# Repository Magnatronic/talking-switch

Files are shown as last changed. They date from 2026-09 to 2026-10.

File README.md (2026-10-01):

# ChatterSwitch – M5StickS3 + Unit Key

Firmware for a big-button accessibility switch: a talking switch (Quick messages), choice-making with Topics,
a Bluetooth/USB keyboard key for an AAC device, and an IR remote (Control), all in one.

## What you need

- M5StickS3
- M5Stack Unit Key (U144) on the StickS3's Grove port – or a 3.5mm switch socket, or a Unit ToF4M distance sensor
  (see *Using a standard 3.5mm switch* and *Touch-free: the ToF sensor*)
- The printed base and cap (`unit-key-big-cap.scad`)
- Arduino IDE 2.x

## Arduino IDE setup

1. **Board package:** Boards Manager → install **esp32 by Espressif Systems**, version 3.3.0 or newer.
2. **Libraries:** Library Manager → install **M5Unified** (it pulls in M5GFX) and **VL53L1X** by Pololu (for the
   ToF distance sensor).
3. **Board:** *ESP32S3 Dev Module*, then set Tools to:

| Setting | Value |
|---|---|
| USB CDC On Boot | **Enabled** – the setup page talks to the switch over it (the firmware won't build without it) |
| Flash Size | 8MB (64Mb) |
| Partition Scheme | Huge APP (3MB No OTA/1MB SPIFFS) |
| PSRAM | OPI PSRAM |
| USB Mode | **USB-OTG (TinyUSB)** (wired USB keyboard + Bluetooth). *Hardware CDC and JTAG* also works, but then the keyboard is Bluetooth only |

These settings are saved in `sketch.yaml` next to each sketch (`TalkingSwitch/` and `ToFTest/`): the Arduino IDE
picks them up when it opens the sketch, and `arduino-cli compile` uses them. If the Tools menu still shows something
else, set it to the table above.

Open `TalkingSwitch/TalkingSwitch.ino` (the sketch keeps its original name; Arduino needs the sketch folder and
`.ino` to share a name). The `partitions.csv` in that folder replaces the
partition layout automatically (2MB for the firmware, ~5.9MB for recordings). Keep it next to the `.ino`.

**Changing the partition layout wipes the recordings and learned IR codes** on the stick at the next upload
(names and settings are kept) – record them again afterwards.

If the screen says **"No PSRAM!"**, change PSRAM to *QSPI PSRAM* and upload again.

In TinyUSB mode the StickS3 still shows up as a COM port (the setup page's Connect list calls it "ESP32S3_DEV –
TinyUSB CDC") and uploads normally reset it automatically. If an upload fails, put the StickS3 into download mode
(see M5Stack's StickS3 docs for the button sequence) and upload again.

## Setup page (USB)

The setup page is `docs/index.html`, published with **GitHub Pages** so anyone setting it up just opens a link in **Chrome or
Edge** (Firefox and Safari can't talk to USB devices). Turn the StickS3 on and plug it in (don't hold the power
button while plugging it in – that starts it for programming), close the Arduino IDE, click **Connect** and pick
**ESP32S3_DEV – TinyUSB CDC**. The switch is set up over the USB cable – no Wi-Fi – and recordings and
typed words stay on the computer.

The page has a tab for each mode – QUICK, TOPICS, KEYBOARD, CONTROL, MOUSE, GAME – then **Voice** and **Settings**, like the
modes on the switch. The tab of the mode the switch is in has a green dot. At the top of each mode's tab is one line:
**In use** (or a **Use** button to switch to that mode), the mode's settings as short chips, and **⚙ settings**,
which opens them (click **?** next to a setting for a one-line explanation; settings that do nothing with the
current choices are hidden). Below that is what the mode uses.

- **Rows:** each message has a name, its length, **▶ Play** (on the switch), **Edit sound** / **+ Add sound**, and
  a **⋯** menu (Listen here, Download .wav, Delete). In QUICK and CONTROL, click a row (or its number) to select it.
- **Sounds, in three steps:** 1 *Make it* – **Type** the words (spoken in the switch's voice; Enter makes it),
  **Record** with the computer's microphone or a headset, or pick an **Audio file**; 2 *Check it* – it plays straight
  away, **▶ Listen** to hear it again; 3 **Save to switch**. It says *Not saved yet* until then, and asks before
  closing without saving. Typing starts from the message's words, or its name; a typed message with no name is
  named after its words.
- **QUICK:** Plays (Selected message / Scan: press twice / Scan: hold & release / Count presses) and the settings
  that go with it; the 4 Quick messages.
- **TOPICS:** Choose from, Choosing, Scan speed, Scan rounds, Stop choice; the 4 **topics** of up to 4 messages
  each (up to 5 seconds per message). With *Choose from: One topic*, **Use** picks the topic.
- **KEYBOARD:** the key (including Left click), a **custom key or shortcut** such as Win+H (dictation) and the
  Bluetooth name; settings: Key action, Press sound, No USB.
- **CONTROL:** 4 remote-control codes, separate from the messages. For each: a name, **Test / Learn**, Delete (⋯),
  and an optional **sound** that the switch says as it sends the code. Settings: IR codes (and scanning settings
  with *Scan*), Press sound.
- **MOUSE:** **Calibrate** (with what it's doing now), a live **Movement** picture (where the stick is, not the
  pointer, and the comfortable range it learnt; **Centre** puts the dot back in the middle), **Pause / Move**, and the connection; settings: Pointer style, Speed left/right, Speed up/down (Follow),
  Speed-up, Steady, Smoothing (Follow), Tilt speed, Dead zone, Directions (Tilt), Dwell click, Switch, Hold to pause, Clutch, Freeze on click, Double-click help, Press sound.
- **Voice:** the switch's **voice** and speed for typed messages and scanning prompts (natural: Emma, Isabella,
  George, Fable; quick: Cori, Alba, Southern English female, Northern English male). It's stored on the switch, so
  every computer uses the same one. Changing it remakes the prompts, and **Remake in this voice** remakes the typed
  messages made in another voice (recorded and uploaded ones don't change).
- **Settings:** the switch's SETTINGS in groups – **Sound** (Volume, Recording boost – which also sets the loudness
  of messages made on the page), **Presses** (Press must last, Ignore repeats), **ToF sensor** (only with one: its
  settings and a live **Sensor test** graph), **Screen and power** (Brightness, Press wakes screen, Sleep after,
  Auto power off), **Switch** (Modes; **Name**: up to 10 characters put in front of the Bluetooth name, e.g. "Sam"
  shows as "Sam ChatterSwitch 7B70"; Forget paired devices) and **About** (firmware, storage – red when nearly
  full, presses since it was turned on, input, USB keyboard). If the page and the switch's firmware don't match,
  the page says **Update the switch** (or to reload the page).
- **Names become prompts:** naming a message, topic or IR code makes its short spoken prompt for scanning, in
  the switch's voice (plus "Back" when choosing from all topics, and "Stop" with Stop choice on). A row says
  *no prompt* when one is missing.

**Typed speech** runs in the browser with two engines. **Kokoro** (the default) sounds much more natural and
takes a few seconds per phrase; **Piper** is almost instant but flatter. Both, and their voices, are served by the
same GitHub Pages site (`docs/tts/`, about 390MB, fetched by `python tools/fetch_tts.py`), so IT only needs to allow
the one `github.io` address. The first use downloads about 115MB for Kokoro (all its voices) or ~80MB per Piper
voice; after that it's cached and works offline. Opening `docs/index.html` straight from disk still does everything
except typed speech.

### Publishing on GitHub Pages

1. Put this folder in a GitHub repository with `git push` (the voice files are ~64MB each: GitHub warns above
   50MB but accepts up to 100MB; they're too big for the web uploader).
2. On GitHub: **Settings → Pages → Build and deployment → Deploy from a branch**, branch `main`, folder **/docs**.
3. After a minute the page is at `https://<account>.github.io/<repository>/`.

To test locally: `python -m http.server 8765 --directory docs`, then open http://localhost:8765.

## Using it

The switch holds **4 Quick messages** (QUICK), **4 Topics of 4 messages** (TOPICS) and **4 IR codes** (CONTROL), each
up to 5 seconds. Each IR code can have its own sound, e.g. IR code 1 "Bubbles" turns the bubble tube on *and* says
"Bubbles!".

**The big switch:** press it. What happens depends on the mode.

| Mode | Big switch does | LED glow |
|---|---|---|
| QUICK | *Plays* setting (and QUICK's *Choosing*): **Selected** – plays the selected Quick message (see *Play style* for hold-to-play and latch; with Tap, keep holding to move to the next Quick message). **Choose one** – by scanning (see below), or by counting presses: 1–4 presses for message 1–4 | message colour: 1 green, 2 blue, 3 purple, 4 orange |
| TOPICS | Messages are **chosen** from the Topics by scanning, see below | colour of the choice on offer |
| KEYBOARD | Holds down the chosen key while pressed. With *No USB* set to QUICK or TOPICS it's also a **backup**: see below | purple |
| CONTROL | Sends the selected IR code, and says its sound if it has one. *IR codes* setting: Selected / Repeat held (keeps sending while held, like a remote's volume button) / Scan (chosen by scanning) | code colour |
| MOUSE | Clicks the mouse button; head or hand movement moves the pointer. See *MOUSE* below | pink |
| GAME | A gamepad button; head or hand movement is a thumbstick (USB). Off at first. See *GAME* below | blue |
| SETTINGS | Keeps doing whatever the previous mode did | as previous mode |

### Touch-free: the ToF sensor

Plug an M5Stack **Unit ToF4M** distance sensor into the Grove port instead of the Unit Key (not together with the
Unit Key or a jack switch – they share the Grove pins) and restart: the switch finds it by itself and it becomes the
switch – every mode, scanning, Press must last and Ignore repeats work as with a button.

- **Line:** a press is coming closer than the *Distance*.
- **Move:** a press is a movement of the *Movement* size towards the sensor from where the hand or finger rests –
  the resting place is learnt as it goes (*Follow*), so it suits small movements like a finger and copes with the
  user shifting. After it has been pressed for the *Settle* time, where the finger is becomes the new resting
  place and it lets go.
- One reading past the line presses (a quick wave counts); it reads about 65 times a second.
- **Setting it up:** SETTINGS → *Sensor test* shows a live graph on the stick, and the setup page's Settings tab
  has a bigger live graph next to the sensor settings, with **Record** to download the readings as a spreadsheet
  file for assessment.
- A finger works best 5–10 cm away; closer than about 4 cm counts as pressed. Mount it rigidly, keep its window
  clean, and point it at a plain background.
- With the sensor there's no switch LED (feedback is on screen and by sound), and the switch doesn't sleep – the
  sensor can't wake it – so the battery runs down faster.

### Just a talking switch

For a switch that only needs to talk, set SETTINGS **Modes: Talking only**: A then goes QUICK → TOPICS →
SETTINGS, and the setup page shows only QUICK, TOPICS, Voice and Settings.

### MOUSE: head or hand movement moves the pointer

The stick's motion sensor works a mouse pointer (SETTINGS **MOUSE mode: Off** hides it), worn on the head (headband or
cap) or on a hand, using whatever movements the user makes (learnt by Calibrate). It goes over USB, or Bluetooth
with the same pairing as KEYBOARD (on an iPad, if no pointer shows, turn on AssistiveTouch).

- **Calibrate:** the first time MOUSE starts, and whenever you choose it (B to **Calibrate**, hold A; or the setup
  page). Wear it as it will be used; it works whichever way round it's worn.
  1. *Keep still* – sit comfortably. This position is the middle.
  2. *Right*, 3. *Left*, 4. *Down*, 5. *Up* – each as far as is comfortable, and back. A beep starts each one;
     the screen shows how far it has gone. It can be any movement: a head turn or nod, a wrist roll or bend.
  From the whole left-to-right and down-to-up range it sets **Speed left/right** and **Speed up/down**, so a full
  comfortable movement crosses about the screen (the screen shows the speeds it chose). They're ordinary settings:
  change them after if needed, e.g. lower for small targets. If a movement isn't seen within 10 s it moves on (Left
  or Up then get the same range as the other side; without Right or Down it keeps the old calibration and speeds). Each time MOUSE starts after that it only needs *Keep still* (a second), unless it's worn at a
  clearly different angle, when it asks for the whole calibration again.
- **Pointer style:** *Follow* (at first): the pointer moves as you move. *Tilt*: like a joystick – hold a little
  away from rest and the pointer keeps going, faster the further you go (full speed at about 70% of the comfortable
  range, so no need to reach the limit); back to rest and it stops. Tilt needs only small movements and has no
  screen-edge problem. Its settings: *Tilt speed*, *Dead zone* (how close to rest keeps still) and *Directions*
  (*4 only*: straight left, right, up or down, never at an angle). Rest is where you are after *Keep still*, after
  a pause, or after **Centre** on the setup page. Nods and wrist rolls are checked against gravity, so they don't
  drift; a head turn can drift a little, and while you rest it slowly settles back.
- **Screen edges** (Follow): the pointer stops at the edge while the head keeps going. That's also how to bring the pointer
  back in line: push into the edge until the head is comfortable again, or use the clutch (below).
- **Clicks:** the big switch is the left (or right, *Switch* setting) button. **Dwell click:** keep the pointer in
  one small area for the *Dwell click* time to click; move away to click again. A green bar on the screen fills up
  before it clicks.
- **Pause:** hold A, or **hold the switch** for the *Hold to pause* time (2 s): two falling notes = paused, two
  rising = moving. With Hold to pause on, a short press clicks when it's let go; set it Off to drag (the button is
  then held while the switch is).
- **Clutch** (with Hold to pause on): holding the switch keeps the pointer still. To bring the pointer back in line,
  hold the switch, turn to look at the pointer (or back to comfortable), and let go: a low note says it won't click.
  Like lifting a mouse off the desk. Moving less than the *Clutch* amount (10°) while holding is still a click.
- **Freeze on click:** the pointer keeps still for a moment (0.3 s) when the switch is pressed and let go, so the
  press doesn't jog it. With Hold to pause on, it also keeps still while the switch is held, so the click lands where
  it was pressed.
- **Double-click help** (off at first): after a click the pointer keeps still for a while (0.5–1.5 s), so a second
  click lands in the same place. It doesn't double-click by itself.
- It doesn't sleep in MOUSE mode.
- The research and step-by-step plan are in [MOUSE-PLAN.md](MOUSE-PLAN.md).

### GAME: head or hand movement is a gamepad thumbstick

Off at first: SETTINGS **GAME mode: On** adds it (the switch restarts, as USB has to start again with the gamepad).
Over **USB only**, the stick is then also a gamepad:
- **On a PC:** it shows in *Set up USB game controllers* (joy.cpl) with no driver. Games that only take Xbox
  controllers need Steam Input (or similar) to use it.
- **On an Xbox:** plug it into a USB port on the **Xbox Adaptive Controller**. Its left stick is the XAC's left
  stick, its right stick the right one. The XAC's USB ports only give a little power unless the XAC has its own
  power supply; the stick can run on its battery.

How it works:
- **Calibrate** is the same as MOUSE (shared, so calibrating in either does both). Rest is the thumbstick in the
  middle; full push comes at about 70% of each side's comfortable range, so a stiff side still gets there.
- Near rest (*Dead zone*) the thumbstick stays in the middle; *Response* makes it finer near the middle.
  *Directions: 4 only* pushes straight left, right, up or down. Nods and wrist rolls don't drift (gravity); a head
  turn settles back to the middle while resting near it.
- **The switch** is a gamepad button (*Switch button*: A, B, X, Y, LB, RB), held while the switch is.
- **Pause:** hold A, or **Pause** on the setup page: the thumbstick goes to the middle. Moving again makes where you
  are the new rest.
- Not over Bluetooth, and it doesn't sleep in GAME mode.

### Backup mode: a switch for the AAC device, and a talker when it isn't there

With KEYBOARD's **No USB** set to QUICK or TOPICS, the switch works an AAC device over USB, and when
there's no USB connection (the device isn't there, is flat, or the cable is out) for 10 seconds it changes to
QUICK or TOPICS by itself, with a falling two-note sound and "No USB" on screen, so it can still talk.
While counting down, the KEYBOARD screen says "No USB – QUICK in 8 s". In the backup mode the bottom line starts
with "Backup", and Bluetooth stays off, so it doesn't use extra battery (and the switch can sleep as usual).
When USB is connected again it goes back to KEYBOARD (rising two notes), once any choice being made is
finished. If it's asleep, that happens when it wakes. Choosing a mode with A (or on the setup page) ends the
backup. Fill the Quick messages and topics with what's needed when the AAC device isn't there.

### Stick buttons – one rule everywhere

The bottom line of the screen always shows what the buttons do right now.

| Button | Does |
|---|---|
| **A click** | Next mode (QUICK → TOPICS → KEYBOARD → CONTROL → MOUSE → GAME → SETTINGS, skipping modes turned off in *Modes* / *MOUSE mode* / *GAME mode*). In a mode's settings, an open topic, About or Sensor test: close it |
| **B click** | Next: Quick message / topic / key / IR code / Calibrate (MOUSE, GAME), then the mode's **Settings** item, then back to the first. In an open topic: its next message. In settings: the next setting. B itself is silent, to save battery |
| **Hold A** | Do it: QUICK – record the selected Quick message (release to stop; if it already has one, the screen says "Hold A again to replace" – hold A again within 4s to record, B keeps it); TOPICS – open the topic, to look through its messages; CONTROL – learn the selected code (remote 30cm+ from the end of the stick, within 8s); MOUSE, GAME – pause / move the pointer (thumbstick), or on **Calibrate** start it; on **Settings** – open them; in settings – next value, or open About / Sensor test |
| **Hold B** | Hear it: QUICK – the selected Quick message; an open topic – the message; CONTROL – the code's sound (without sending it); in settings – back a value |

A hold is 0.6s. When the screen is off, the first press of A or B only wakes it; when it's just dim, presses work
as normal.

### Scanning: choice-making with one switch

With QUICK's *Plays* set to **Choose one** (Press twice or Hold & release) or CONTROL's *IR codes* to **Scan**, and in TOPICS, the switch offers the choices one at a time – each with
its LED colour, its name on screen and a short **spoken prompt** played quietly ("Toast"… "Crisps"… "Yoghurt") –
and one is picked, which then plays in full (or, in CONTROL, is sent).

- **QUICK, Plays: Choose one** – it offers the 4 Quick messages. The simplest start.
- **TOPICS, Choose from: One topic** (default) – it offers the messages in the selected topic (B on the switch, or *Use* on the
  setup page), e.g. "Snack time".
- **TOPICS, Choose from: All topics** – it offers the **topics** first ("Snack time"… "Music"…), then the chosen topic's
  messages and **"Back"** (to return to the topics).
- **Offer Quick / Offer Control / Offer My device** (with All topics) – more choices next to the topics, so TOPICS
  can be the home screen: **Quick** offers the Quick messages and **Control** the IR codes, like a topic's
  messages (then Back), so the user can say a Quick message or turn on the bubble tube or TV themselves; **My
  device** changes the switch to KEYBOARD so they can use their AAC device or computer.
  Once in KEYBOARD every press goes to the device, so the switch can't offer a way back: bring it back with A (or
  the setup page), or with *No USB: TOPICS* it comes back by itself when USB is unplugged.
- **Choosing: Press twice** – a press starts the offers, the next press chooses. With no choice it stops after the
  set number of *Scan rounds*.
- **Choosing: Hold & release** – hold the switch to step through the offers, let go to choose. After choosing a
  topic, hold again for its messages.
- **Stop choice: On** – every scan ends with **"Stop"** (LED red): the topics, a topic's messages (after "Back"),
  and QUICK's and CONTROL's choices. Choosing it ends the scan without doing anything; the next press starts again
  from the top. It lets the user say "none of these". A or B on the stick also stops a scan.

Only topics and messages that are set up are offered, so two messages make a simple two-way choice. Prompts are
made by the setup page from the **names**. A message without a prompt – e.g. one just recorded on the stick – plays
itself quietly as its prompt (cut short by the next offer), so scanning works straight away with no setup page:
record the Quick messages (QUICK, hold A) and set QUICK's *Plays: Choose one*.

### Settings

Each mode has its own settings – press B until the screen shows **Settings**, then hold A to open them – and the
**SETTINGS** mode holds the general ones. In any settings: **B** = next setting, **hold A** = next value, **hold B** = back a value,
**A** = close (or next mode). Changes are saved straight away; settings close by themselves after 30s untouched.
Settings that do nothing with the current choices are left out (e.g. Scan speed when the selected message plays).
All of these are on the setup page too, on each mode's tab and the Settings tab.

| Where | Setting | Choices (default **bold**) | What it does |
|---|---|---|---|
| General | Volume | 1, 2, **3**, 4 | How loud messages play |
| General | Modes | **All**, No KEYBOARD, No CONTROL, Talking only | Turn KEYBOARD and/or CONTROL off for a switch that only talks: A skips them, the setup page hides their tabs, and their settings (and the matching Offer settings) go too. Their key and IR codes are kept |
| General | MOUSE mode | Off, **On** | The MOUSE mode (see above) and its tab on the setup page. Off: A skips it and the tab is hidden |
| General | GAME mode | **Off**, On | The GAME mode (see above) and its tab. The switch restarts when it changes. Needs USB Mode: USB-OTG (TinyUSB) |
| General | Press must last | **Instant**, 0.1s, 0.25s, 0.5s, 1s | Filters accidental brushes |
| General | Ignore repeats for | Off, 0.2s, **0.4s**, 0.8s, 1.5s | Filters tremor and bounces after a press |
| General (sensor) | Sensor mode | Line, **Move** | Only with a ToF sensor plugged in – see *Touch-free: the ToF sensor* |
| General (sensor) | Distance | 5, 6, 8, **10**, 15, 20, 30, 50 cm | Line: closer than this counts as a press |
| General (sensor) | Movement | 5, **8**, 10, 15, 20, 30 mm | Move: a movement this big towards the sensor counts as a press |
| General (sensor) | Settle | Off, 1, **2**, 3, 5 s | Move: after being pressed this long, where the finger is becomes the new resting place and it lets go. Off for users who hold presses on purpose |
| General (sensor) | Follow | Slow, **Medium**, Fast | Move: how quickly the resting place follows drift |
| General (sensor) | Ignore beyond | Off, 20, **30**, 50 cm | Anything further away counts as nothing there |
| General (sensor) | Sensor test | hold A | A live graph of the sensor with a press count; presses only beep there. B restarts the count, A closes |
| General | Brightness | Low, **Medium**, High | Screen brightness while in use. Low saves battery |
| General | Press wakes screen | **No**, Yes | Whether presses of the big switch light up the screen |
| General | Sleep after | Off, 2 min, **5 min**, 15 min | On battery, with no presses: sleep to save power. The big switch still works (see below) |
| General | Auto power off | **Never**, 30 min, 60 min, 2 hours | On battery, with no presses: turn off completely, e.g. at the end of the day |
| General | Recording boost | Off, Low, **Medium**, High | Makes recordings made on the switch louder, at the cost of some harshness |
| General | Forget BT devices | hold A, then again to confirm | Clears every paired computer/tablet. Also remove the switch in that device's Bluetooth settings |
| General | About | hold A to open | The firmware version, the switch's name, how much recording storage is used, presses since it was turned on, and the input (switch or ToF sensor). A closes |
| QUICK | Plays | **Selected**, Choose one | *Selected*: plays the selected Quick message (Play style and Hold for next msg apply). *Choose one*: one is chosen – see QUICK's Choosing. The setup page shows Plays and Choosing as one setting |
| QUICK | Choosing | **Press twice**, Hold & release, Count presses | Kept in step with TOPICS and CONTROL's Choosing (change Press twice / Hold & release in one and the other follows); only Count presses is QUICK's own – TOPICS and CONTROL (and the Quick choice inside TOPICS) always scan. *Press twice* / *Hold & release*: scanning, see above (Scan speed, Scan rounds, Stop choice apply). *Count presses*: press 1–4 times quickly for message 1–4 – each press ticks and the LED shows that message's colour; the message plays after the Press gap. Not for users with tremor or accidental double presses |
| QUICK | Press gap | 0.5s, **0.8s**, 1.2s, 1.6s, 2s | Count presses: how long without a press ends the count – longer for users who are slower to release and press again (every message waits this long before playing). Ignore repeats only filters bounces under 0.15s in this mode |
| QUICK | Play style | **Tap**, Hold to play, Latch | *Tap*: a press plays the whole message. *Hold to play*: plays (looping) only while the switch is held – classic cause and effect. *Latch*: one press starts it looping, the next press stops it |
| QUICK | Hold for next msg | Off, 1s, **1.5s**, 2s, 3s | With Tap: how long the switch is held to move to the next Quick message. Turn off if letting go quickly is hard |
| TOPICS | Choose from | **One topic**, All topics | See above |
| TOPICS | Offer Quick | **Off**, On | With All topics: offers "Quick" (the Quick messages) next to the topics, see above |
| TOPICS | Offer Control | **Off**, On | With All topics: offers "Control" (the IR codes) next to the topics |
| TOPICS | Offer My device | **Off**, On | With All topics: offers "My device" (changes to KEYBOARD) next to the topics |
| TOPICS, CONTROL | Choosing | **Press twice**, Hold & release | See above |
| QUICK, TOPICS, CONTROL | Scan speed | 1.5s, 2s, **3s**, 4s, 5s | How long each choice is offered |
| QUICK, TOPICS, CONTROL | Scan rounds | 1, **2**, 3 | Press twice: how many times round before it stops by itself |
| QUICK, TOPICS, CONTROL | Stop choice | **Off**, On | Offers "Stop" last, to choose none of them |
| KEYBOARD | No USB | **Bluetooth**, QUICK, TOPICS | What to do when the switch isn't plugged into a computer or AAC device by USB. *Bluetooth*: send the key over Bluetooth instead. *QUICK* / *TOPICS*: after 10 seconds, talk instead, using that mode – Bluetooth stays off to save battery. Plugging USB back in switches it back to KEYBOARD (see the backup mode above). Only with USB Mode: USB-OTG (TinyUSB) |
| KEYBOARD | Key action | **Momentary**, Latch | *Momentary* holds the key while the switch is held; *Latch* – one press holds the key down, the next lets it go. The screen says "Key held" and the LED glows brighter while latched |
| KEYBOARD, CONTROL, MOUSE, GAME | Press sound | **Off**, Click, Beep | A sound on each press, as feedback (CONTROL: only for codes with no sound of their own) |
| CONTROL | IR codes | **Selected**, Repeat held, Scan | See the CONTROL mode above |
| MOUSE | Pointer style | **Follow**, Tilt | Follow: the pointer moves as you move. Tilt: hold away from rest and it keeps going; back to rest and it stops |
| MOUSE | Tilt speed | 1–5 (**3**) | Tilt: the fastest the pointer goes |
| MOUSE (Tilt), GAME | Dead zone | 2°, **4°**, 6°, 9° | This close to rest nothing moves (shared) |
| MOUSE (Tilt), GAME | Directions | **Any**, 4 only | 4 only moves straight left, right, up or down (shared) |
| MOUSE | Speed left/right, Speed up/down | 1–8 (**4**, **3**) | How fast the pointer moves each way. Calibrate sets them so a full comfortable movement crosses the screen; change them after if needed. The computer's pointer speed also applies |
| MOUSE | Speed-up | Off, Low, **Medium**, High | Faster movements go further, so slow ones stay precise |
| MOUSE | Steady | Off, **Low**, Medium, High | Ignores turns slower than this – steadies tremor and drift |
| MOUSE | Smoothing | Off, **Low**, Medium, High | Smooths out shakes, with a little lag |
| MOUSE | Dwell click | **Off**, 0.8, 1, 1.5, 2, 3 s | Time in one place to left-click |
| MOUSE | Dwell area | Small, **Medium**, Large | How far the pointer may wander and still count as one place |
| MOUSE | Switch | **Left click**, Right click | The button the big switch presses |
| MOUSE | Hold to pause | Off, 1 s, **2 s**, 3 s | Holding the switch this long pauses / moves the pointer; short presses click when let go. Off: the button is held while the switch is (drag) |
| MOUSE | Clutch | Off, 5°, **10°**, 15° | With Hold to pause on: the pointer keeps still while the switch is held; moving more than this while holding re-lines the head, with no click |
| MOUSE | Freeze on click | Off, 0.2 s, **0.3 s**, 0.5 s | The pointer keeps still this long when the switch is pressed and let go (and while held, with Hold to pause on) |
| GAME | Stick | **Left**, Right | Which thumbstick the movement is |
| GAME | Switch button | **A**, B, X, Y, LB, RB | The gamepad button the switch is, held while the switch is |
| GAME | Response | Straight, **Gentle**, Very gentle | Gentle: finer near the middle, full at the comfortable limit |
| MOUSE | Double-click help | **Off**, 0.5 s, 1 s, 1.5 s | After a click the pointer keeps still this long, so a second click lands in the same place |

### The screen

- **Top bar:** the mode, in its colour ("SETTINGS" on that colour while its settings are open); on the right, the
  volume (a speaker and 4 bars) and the battery (% and icon; green bolt = charging, red = low).
- **Middle:** three lines, the same on every screen – the main thing (big), its state or what to do (green ready,
  orange a problem, yellow what to do), and details (grey). What the switch will do – the Quick message; in TOPICS the topic B is on and its messages (or the
  choice on offer while scanning); the key and whether it's sending by USB or Bluetooth; or the IR code. When scanning, QUICK and
  CONTROL still show the selected message or code (the one B and hold A work on), with "Scans…" underneath.
- **Bottom:** what the buttons do right now.
- A white frame appears while the big switch is held down.

Recordings are trimmed and boosted automatically, stored in flash, and survive power-off.

**To delete a Quick message:** select it (B in QUICK), then hold A, and hold it again ("Hold A again to replace") for a couple of seconds *without speaking*, and
let go. The screen says "Nothing heard – cleared". Or use ⋯ › Delete on the setup page (topic messages are made there).
Mode, selected Quick message, topic and IR code, key and settings are remembered too.

**Recording tips:** speak 10–15cm from the stick in a normal voice. The recording is cleaned up automatically:
silence trimmed, hiss between words turned down, level evened out.

### Keyboard (USB or Bluetooth)

Keys: **Space, Enter, Up, Down, Left, Right, Left click**, and a custom key or shortcut set on the setup page (B-click to choose). In Grid 3 / Mind Express,
set switch input to the key shown on screen.

**Left click** clicks the left mouse button wherever the pointer is (it doesn't move the pointer). With *Key action:
Latch* it holds the button down until the next press, for dragging. On an iPad the pointer only shows with
AssistiveTouch on.

- **USB:** plug into the computer with a data cable. Nothing to pair, and it charges at the same time.
- **Bluetooth:** the StickS3 appears as **"ChatterSwitch XXXX"** – each stick has its own 4-character ID, shown on the
  KEYBOARD screen, so you can tell switches apart – with any *Switch name* from the setup page in front, e.g.
  "Sam ChatterSwitch 7B70". Pair it from Windows, iPad or Android like a keyboard (it's a keyboard and mouse in
  one, for Left click).
  To move it to a different computer or tablet, use *Forget BT devices* in SETTINGS.
  **Paired before Left click was added (28 Sep 2026)?** Remove the switch in the device's Bluetooth settings, use
  *Forget BT devices* on the stick, and pair again – the device remembers it as keyboard-only.

It picks automatically: when a computer is using it as a USB keyboard, keys go over USB only;
otherwise over Bluetooth. A phone charger doesn't count, so Bluetooth keeps working while charging.
The screen says which is in use.

### Power saving

- The screen dims after 30s and switches off after 2 minutes without a press of A or B. Its brightness while
  in use is the *Brightness* setting (Low saves the most).
  The big switch keeps working with the screen off.
- Bluetooth only runs in KEYBOARD and MOUSE modes (it starts after a second or so in that mode; pairing is remembered).
- **Sleep:** on battery, after the *Sleep after* time with no presses, the StickS3 sleeps – screen, speaker
  and radio off. The switch LED keeps glowing. **The big switch still works:** a press wakes it and does its
  job (a fraction of a second slower than normal). A or B wakes it too.
  It doesn't sleep in KEYBOARD mode over Bluetooth, because the connection would drop, in MOUSE or GAME mode, or with the
  ToF sensor, which can't wake it.
- **Auto power off** (off by default): after the chosen time with no presses it beeps three times and shows
  a warning; 30s later it powers off. Press any button to cancel. Press the power button to turn it back on.
- It never sleeps or powers off while plugged into USB.
- A "Low battery" warning appears at 15%.

### Press logging

Every press of the big switch is written to the USB serial port (115200 baud) as
`press,<milliseconds since boot>,<mode>` – handy evidence for assessing
intentional communication. SETTINGS → About (and the setup page's About box) shows how many since it was turned on.

## Tuning in code

Most settings are in the SETTINGS mode above. At the top of `TalkingSwitch.ino`:

| Setting | Default | What it does |
|---|---|---|
| `DEBOUNCE_MS` | 25 | Contact bounce filter |
| `MAX_SECONDS` | 5 | Longest recording per message |
| `MIC_PGA` | 8 | Microphone analogue gain (3dB steps, 0–10). Lower it if loud voices sound distorted |
| `SCREEN_DIM_MS` / `SCREEN_OFF_MS` | 30000 / 120000 | Screen dims, then switches off, when idle |
| `BLE_NAME` | "ChatterSwitch" | Default Bluetooth name; each stick's own ID is added to it |
| `FW_VERSION` / `FW_API` | "30 Sep 2026" / 3 | Version shown in About. Raise `FW_API` (and `PAGE_API` in `docs/index.html`) when the page and firmware must change together |

## Troubleshooting

- **Won't compile, with errors about `io_pin_remap.h`, `pinMode` or `tone` in M5Unified:** the board is set to
  *Arduino Nano ESP32*. Choose **Tools → Board → esp32 → ESP32S3 Dev Module** and the settings above.
- **Won't compile: "Set Tools > USB CDC On Boot: Enabled":** set **Tools → USB CDC On Boot → Enabled** (and check
  the other settings above). The IDE keeps Tools settings between sketches, so they can change while you're working
  on another one. MouseTest uses the same settings.
- **Big switch does nothing:** with a jack switch, try the other Grove wire (see below). With the Unit Key, swap
  `PIN_KEY` (10) and `PIN_LED` (9) in the code – the Grove wire order can vary. With the ToF sensor, check About
  says *Input: ToF sensor* – the switch only looks for it when it starts, so plug it in, then turn it on.
- **Recordings hiss or distort:** hiss – speak closer and lower Recording boost; distortion on loud voices – lower `MIC_PGA`.
- **IR only works close up:** the StickS3's IR LED is small (it's in the end of the stick). Point that end straight at
  the device – its IR window is usually on the front – ideally within 3–5m. In a dark sensory room, bouncing off a
  white wall or ceiling can help. For longer range, an IR repeater/extender near the device works with any remote.
- **IR learns nothing:** make sure the remote is 38kHz (most TV remotes are) and point it at the StickS3's IR window from **30cm to 1m** – closer than 30cm can scramble the code. Very long air-con codes may be cut short.
- **Quiet playback:** raise *Volume* in SETTINGS (or on the setup page's Settings tab); for a noisy classroom add
  a small external speaker.
- **After an upload the switch shows as "USB JTAG/serial debug unit" and doesn't answer:** it's waiting in download
  mode instead of running the firmware – press the stick's power button once to restart it. It then shows as
  "ESP32S3_DEV – TinyUSB CDC" on a different COM port.
- **The page says the switch didn't answer:** check *USB CDC On Boot: Enabled* and close the Arduino Serial Monitor.
  The Connect list always calls the switch "ESP32S3_DEV – TinyUSB CDC" (the switch's own name is used for Bluetooth).
- **Using a standard 3.5mm switch instead:** cut a Grove cable and wire a 3.5mm mono socket to two of its wires:
  **yellow** (the switch signal, GPIO10) and **black** (ground) – either way round, as a switch just joins them. Cut the
  red (5V) and white wires short and cover them. If it doesn't respond, colours vary between cables: try white instead
  of yellow. The thin wires hold better in screw terminals if twisted and folded back. Not together with the ToF sensor
  (it uses the same wires).

## ToF sensor test (touch-free switch)

`ToFTest/ToFTest.ino` is a separate test sketch for the M5Stack **Unit ToF4M** (VL53L1X) on the Grove port, to try it as
a touch-free switch (a hand, head or foot moving closer than a set distance) and to watch a user's movement. It
needs the **VL53L1X** library by Pololu (Library Manager). Unplug the Unit Key and any switch on the mono jack first –
they share the Grove pins. Two ways to press: **LINE** – closer than a set distance (5–50 cm); **MOVE** – a movement of 5–30 mm towards the
sensor from where the hand or finger rests (best for small movements like a finger). The screen shows a scrolling
graph that zooms to fit, with the trigger line. A = size, hold A = LINE / MOVE, B = reset, **hold B = settings**
(B next, hold A change, A close):

| Setting | Choices | What it does |
|---|---|---|
| Mode | LINE, **MOVE** | How a press is detected |
| Distance | 5, 6, 8, **10**, 15, 20, 30, 50 cm | LINE: press closer than this |
| Movement | 5, **8**, 10, 15, 20, 30 mm | MOVE: press on a movement this big towards the sensor |
| Settle | Off, 1, **2**, 3, 5 s | MOVE: after being pressed this long, where the finger is becomes the new resting place (so it can't stay stuck pressed) |
| Follow | Slow, **Medium**, Fast | MOVE: how quickly the resting place follows drift. Slow catches slow presses; Fast copes with restless movement |
| Ignore beyond | **Off**, 20, 30, 50 cm | Anything further away counts as nothing there – stops people passing by from pressing |
| Field of view | **Wide**, Medium, Narrow | Narrower ignores movement at the sides, but the finger must be right in front |
| Smoothing | **Off**, 3 readings | The middle of the last 3 readings: removes single spikes, ~30 ms later |
| Too close | **Pressed**, Nothing | Closer than the sensor can measure (~4 cm) |
| Range | **Short**, Long | Short: up to ~1.3 m, ~65 readings a second, better in sunlight. Long: ~4 m, slower |

The sensor isn't reliable closer than about 4 cm, and a finger works best 5–10 cm away. Mount it rigidly, keep its
window clean, and point it at a plain background. Readings also go to the serial port for the Serial Plotter – open it
after the stick has started.

## Mouse test (motion sensor as a mouse)

This is now ChatterSwitch's MOUSE mode (above); the test sketch stays for trying new ideas first.
`MouseTest/MouseTest.ino` is a separate test sketch: the StickS3's motion sensor moves the pointer, worn on the head
(headband or cap) or held in the hand. Turn left/right to move left/right, tip down/up to move down/up. It works over
USB, or Bluetooth as "ChatterSwitch XXXX" (the same identity as ChatterSwitch, so a paired device keeps working).

- **Clicks:** the big switch is the left button (held while the switch is, so it drags) or the right button
  (*Switch* setting). **Dwell click:** keep the pointer in one small area for the *Dwell* time to click; move away to
  click again.
- **Calibrate** (hold A; also at the first start): *Keep still*, then *Tip down* – nod down or tip the front down,
  then back. This works whichever way round the stick is worn – calibrate it the way it's worn. Later starts
  only need *Keep still*, unless it's worn at a clearly different angle, when it asks for *Tip down* again.
- **Buttons:** A = pause / move, hold A = calibrate, B = next speed, hold B = settings (B next, hold A change,
  A close).
- The screen shows the turn as a dot in a box (the grey ring is *Steady*). The rates also go to the Serial Plotter.

| Setting | Choices | What it does |
|---|---|---|
| Speed | 1–6 (**4**) | How far the pointer goes per turn. The computer's pointer speed also applies |
| Speed-up | Off, Low, **Medium**, High | Faster turns go further, so slow turns stay precise |
| Steady | Off, **Low**, Medium, High | Ignores turns slower than this – steadies tremor and drift |
| Smoothing | Off, **Low**, Medium, High | Smooths out shakes, with a little lag |
| Dwell click | **Off**, 0.8, 1, 1.5, 2, 3 s | Time in one place to click |
| Dwell area | Small, **Medium**, Large | How far the pointer may wander and still count as one place |
| Switch | **Left click**, Right click | What the big switch does |
| Flip left/right, Flip up/down | **Off**, On | If the pointer goes the wrong way |

## Notes

- Compile-checked against esp32 core 3.3.11 with M5Unified 0.2.23 / M5GFX 0.2.30 and VL53L1X 1.3.1, in both USB
  modes.
- Tested on hardware: the Unit Key and a 3.5mm jack switch, the modes and their settings, the setup page, and the
  ToF sensor (Line and Move), IR (learning and sending), Left click over USB. Not yet tested on hardware: Left click
  over Bluetooth, the USB keyboard, sleep, auto power-off and the backup
  mode.
- This is a DIY device, not a certified AT product. Check it's robust and safe for each user before use.

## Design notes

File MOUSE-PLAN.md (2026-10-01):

# MOUSE mode – research and plan

This is where the ChatterSwitch MOUSE mode stands and what comes next, so work can pick up from here.
We build it **one step at a time**, testing each step on the stick before starting the next.
New ideas can be tried in `MouseTest/` first.

**Targets:** Windows PCs and iPads (USB, or Bluetooth with the same pairing as KEYBOARD).
**Users:** college; the stick is worn on the head (headband or cap) or on a wrist or hand.

## Status

| Step | What | State |
|---|---|---|
| 1 | MOUSE mode in ChatterSwitch (from MouseTest), hold to pause, setup page tab | **Done, tested 30 Sep 2026** (commits 369e680, a447b3f; on by default) |
| 2 | Training on the user's own movements, speeds set by Calibrate, live picture on the page | **Built 30 Sep–1 Oct 2026, to test** (no turn limit, see below) |
| 3 | Freeze on click, double-click help, clutch | **Built 1 Oct 2026, to test** (ignore jerks and Centre dropped) |
| 4 | Tilt (joystick) style for very small movements | **Built 1 Oct 2026, to test** |
| 5 | True screen position (absolute pointer) | Only if 2–4 aren't enough |
| 6 | GAME mode: movement as a thumbstick, for PC and Xbox | **Built 1 Oct 2026, to test** (straight into ChatterSwitch, no GameTest) |
| – | Head gestures (Quha style) | Idea, see the end |

## What we found (research, 30 Sep 2026)

**The edge problem.** The stick sends "move by this much", like any mouse, so it never knows where the pointer is.
At the edge of the screen the pointer stops but the head keeps turning; turning back moves the pointer straight
away, so "straight ahead" has shifted and the user ends up looking sideways at the screen.
- The commercial gyro head mice (**Quha Zono**, **GlassOuse**) behave the same way. Their manuals present it as the
  way to re-centre: push the pointer into the edge on purpose and keep turning. Fine as a trick, a fault by accident.
- Quha also has head gestures for pause, scroll and **cursor centring**, separate horizontal/vertical speed, and a tremor filter.

**Comfortable movement.** Comfortable head turn is about ±30°, and the maximum is about ±55°. Nodding range is smaller.
People with CP often move further one way than the other. One person testing a head-worn IMU joystick had a sore
neck after 10 minutes, so keep the movement needed small and make pausing easy.
- The current default (Speed 4 = 30 counts/°) needs about ±32° to cross a 1920-pixel screen, right at the comfortable limit.

**Two ways to map movement to the pointer:**
- **Follow (position/velocity of the turn → pointer movement):** what we have now. Fast.
- **Tilt / joystick (angle from rest → pointer speed):** hold a tilt and the pointer keeps going; back to rest
  and it stops. It needs only a few degrees of movement and has no edge problem. It doesn't drift because it uses
  gravity. A RESNA study of 15 wheelchair users (8 with CP) found it slower but clearly **more accurate: 86% vs 69%**.
  A 4-direction, fixed-speed variant exists for users with poor control.

**Wrist use.** The movement is different: a wrist is more likely to roll or bend than turn about the vertical.
So calibration must learn *whatever* two movements the user can make, not assume a head turn.

**True screen position (absolute HID).** The stick could say "pointer at x,y", so head angle maps exactly to
screen position. It works on Windows over USB, but reports over Bluetooth are mixed and iPad support is unclear.
It would also need a new report map, so every device would have to pair again. Last resort.

**Other gaps:** pressing the switch jogs the pointer; spasms throw it; the user needs to pause without help
(talking, resting, looking away).

Sources: [Quha Zono X](https://www.quha.com/products/quha-zono-x/),
[GlassOuse FAQ](https://glassouse.com/faq/),
[GlassOuse V1.4 manual](https://glassouse.com/wp-content/uploads/2022/09/GlassOuse-V1.4-user-manual.pdf),
[RESNA: joystick mouse emulation](https://www.resna.org/sites/default/files/legacy/conference/proceedings/2004/Papers/Research/CAC/Joymouse.html),
[Head-mouse, joystick mode](https://arxiv.org/html/2006.13503v1),
[Hackaday: IMU joysticks (UCPLA)](https://hackaday.io/project/173454-2020-hdp-dream-team-ucpla/log/180274-exploring-alternative-computer-input-devices-imu-joysticks),
[Neck range of motion and head control](https://www.researchgate.net/publication/9036081_Neck_range_of_motion_and_use_of_computer_head_control),
[Heads Will Roll: head pointing](https://dl.acm.org/doi/10.1145/3694907.3765916).

## Decisions made

- Build into ChatterSwitch as MOUSE mode; **on by default** (SETTINGS *MOUSE mode: Off* hides it). Keep MouseTest for experiments.
- Stick buttons follow the usual rule: A = next mode, **hold A = pause/move**, B steps to **Calibrate**, then Settings.
- **Pause with the switch:** *Hold to pause* setting (Off, 1, **2**, 3 s). With it on, a short press
  clicks on release; Off = the button is held while the switch is (drag). One switch input only (Grove GPIO10);
  a second switch on the other Grove wire (GPIO9, the Unit Key LED) is possible later if needed.
- **Training covers all four directions** (right, left, down, up), each as far as is comfortable, so each side
  gets its own range.
- Keep relative mouse reports (no re-pairing).
- **No turn limit or automatic re-centring for now** (decided 30 Sep 2026). The edge is the re-centring, as on the
  Quha and GlassOuse: push into the edge until the head is comfortable, or pause and move back. It also lets people
  with a small or one-sided range "ratchet" across the screen. Add the turn limit later as an option only if testing
  shows people losing the pointer.

## Step 1 – what exists now (TalkingSwitch.ino)

- Mode `M_MOUSE` (between CONTROL and SETTINGS), colour pink, settings group `G_MOUSE`.
- The mouse section after `releaseKey()` has calibration, movement, dwell and switch handling.
  Main functions: `updateMouse()` (called from `loop`), `mouseCalSample()`, `mouseMoveSample()`,
  `mouseSendMovement()`, `mouseDwell()`, `mouseSwitch()`, `mousePause()`, `mouseStartCal()`.
- Calibration: *Keep still* (gyro zero point plus "up" from gravity), then *Tip down*, which learns the up/down turn axis.
  Left/right is always the turn about "up". The axes are saved in prefs `m_up` and `m_down`. Each start only needs
  *Keep still*, unless the stick is tilted more than 25° from last time.
- Settings: `m_speed`, `m_accel`, `m_steady`, `m_smooth`, `m_dwell`, `m_area`, `m_switch`, `m_hold`, `m_flipx`,
  `m_flipy`, plus the shared `s_psound`. `s_mouse` turns the mode on and off.
- Serial commands `MCAL` and `MPAUSE 1|0`. INFO has
  `mouse:{cal, step, paused, imu}`. FW_API / PAGE_API = 3.
- Bluetooth runs in MOUSE too; no light sleep in MOUSE.
- Setup page: MOUSE tab with a Calibrate button (it watches the stick every second while calibrating), a Pause/Move
  button, the connection, and the settings panel.

## Step 2 – training (built; the design as planned, without the turn limit)

**What was built:** the 5-step training below (`MC_REST`, `MC_RIGHT`, `MC_LEFT`, `MC_DOWN`, `MC_UP` in
`mouseCalSample()`); the axes come from Right − Left and Down − Up (up/down made at right angles to left/right),
ranges from each peak (a missed Left or Up copies the other side). Prefs `m_up`, `m_x`, `m_y`, `m_rng` (the old `m_down` is unused, so it asks to calibrate
once). Movement is still "follow". **Speed (changed 1 Oct 2026, after research):** two ordinary settings,
*Speed left/right* (`m_spdx`) and *Speed up/down* (`m_spdy`), in counts per degree (8–100). Calibrate sets them
from the whole span (right+left, down+up) so it crosses about 1920 × 1080 counts, picks the nearest choice, and
shows them ("Speed 6 / 4"); they can be changed after. This is how Enable Viacam does it (Quha also has separate
H/V speeds). No product found sets left and right separately, and head-pointer research puts the best gain well
below a hand mouse's, so the speed must stay adjustable. Per-side speeds were tried and dropped; an optional
*Even out sides* can come later if a strongly one-sided user needs it. Flip settings removed (training learns the
directions). Small wear changes at start turn the axes with "up". Setup page: live picture (`MSTREAM 1|0`,
`mou,<step>,<x×10>,<y×10>,<paused>` lines), INFO `mouse.range`. FW_API / PAGE_API = 4.
The picture's dot is the angle since the last Keep still, pause or `MZERO` (the page's Centre button), so it drifts
slowly (about 0.07°/s measured) and doesn't follow edge pushes. FW_API / PAGE_API = 6 since the two speed settings.
Stream checked on the stick 30 Sep 2026: right, left, down, up all come out the right way.

The original design (turn limit parts not built):

**Training routine** (replaces Keep still + Tip down; the stick talks you through it; also started from the page):
1. **Rest** – sit comfortably, keep still. Learns the gyro zero point, gravity, and the **rest position = centre**
   (which need not be straight ahead).
2. **Right** as far as is comfortable, and back → the left/right axis (whatever movement it is: head turn, wrist
   roll…) and the right range (the peak angle).
3. **Left**, and back → the left range (and confirms the axis).
4. **Down**, and back → the up/down axis and the down range.
5. **Up**, and back → the up range.

For each step: it starts when the movement passes a small threshold, records the peak angle along the axis,
and finishes when the stick is back near rest and still. If nothing happens within about 10 s, it says so and
uses a small default range, or keeps the old one. Beeps and the screen show each step.
Save the axes, the ranges and the rest position in prefs.

**Turn limit (fixes the edge problem):** keep an angle from centre on each axis. The pointer only moves while that
angle is inside the trained range. Past the range, the pointer waits until the user comes back inside.
- Map each side's range to slightly **more** than half the screen (about 1.2×). Then reaching the limit always
  pins the pointer to that screen edge, and **every visit to an edge puts head and pointer back in step**. This
  works even with Windows/iPad pointer acceleration.
- **Speed** becomes "how much of the screen the trained range covers" (e.g. Reach: 80/100/120%), so each side
  gets its own gain from its own range. Speed-up may need to be off, or limited, in this style.
- **Drift:** up/down can be corrected from gravity (a complementary filter) when the axis is a tilt. Left/right
  relies on the zero-point correction plus the edge re-sync.
- **Centre:** make "where I am now" the new straight ahead. Idea to test: resuming from pause keeps the pointer
  where it is and takes the current position as matching it.

**Setup page:** the training driven from the page, with a live picture of the movement and the learnt ranges
(the stick streams angles, like the ToF sensor's `SENSE` stream).

**To test:** on the head and on a wrist; Windows and iPad; asymmetric range (pretend one side is stiff);
turning past the edge and back should no longer leave the user looking sideways.

## Step 3 – filters

- **Freeze on click (built 1 Oct 2026):** setting *Freeze on click* (`m_freeze`: Off, 0.2, **0.3**, 0.5 s).
  The pointer keeps still that long after the switch goes down and after it comes up (`mouseFreeze()`, called on
  the debounced change, before *Press must last*, since the jog comes with the press). With *Hold to pause* on, it
  also keeps still the whole time the switch is held (the click comes on letting go, so it lands where pressed).
  Movement not sent yet is dropped; the smoothing and the live picture keep running. FW_API / PAGE_API = 7.
- **Double-click help (built 1 Oct 2026)** (Quha's "double-click assistant"): setting *Double-click help*
  (`m_double`: **Off**, 0.5, 1, 1.5 s). After a click (switch or dwell, `mouseClicked()`) the pointer keeps still
  that long, so a second click lands in the same place. It doesn't double-click by itself. A click within the time
  (+0.3 s) is the second one and doesn't hold the pointer again. Kept separate from freeze on click: that one is
  short and for every press, this one longer and only wanted by some.
- **Clutch (built 1 Oct 2026):** the switch works like lifting a mouse off the desk. Setting *Clutch* (`m_clutch`:
  Off, 5°, **10°**, 15°), only with *Hold to pause* on (Off holds the button to drag). While the switch is held the
  pointer keeps still. If the head moves further than the setting from where it was when the switch went down
  (straight-line angle, so tremor doesn't add up), it is a clutch: a low note (600 Hz), no click on letting go, and
  no Hold to pause. Re-centring is then one natural move: hold, look back at the pointer, let go. It also lets a
  small or one-sided range step across the screen. Found in no head mouse (Quha and GlassOuse use edge pushes or
  gestures). `mouseSwitchEdge()` on the debounced change; letting go clears the smoothing so the move doesn't leak.
  **To test:** whether people who move while pressing lose clicks (then a bigger setting, or size it from the
  Keep still wobble).
- **Dropped (1 Oct 2026, decided not needed):** *ignore jerks* (a movement faster than a limit is ignored) and
  *Centre* (push the pointer into a corner, then half the span to the middle). The clutch covers re-lining.
- Up/down and left/right speed are separate already (step 2).

## Step 4 – tilt (joystick) style

**Built 1 Oct 2026, to test.** FW_API / PAGE_API = 8.
- *Pointer style* (`m_style`): **Follow** (steps 1–3) or **Tilt**. Tilt settings (shown only in Tilt, on the stick
  and the page): *Tilt speed* (`m_tspeed`, 300–1800 counts/s, **800**), *Dead zone* (`m_dead`, 2/**4**/6/9°),
  *Directions* (`m_dirs`, **Any** / 4 only: the most-tipped axis only). Follow's speeds, Speed-up, Steady and
  Smoothing are hidden in Tilt.
- Speed = top × f², f = 0 at the dead zone edge to 1 at `MS_TILT_FULL` (70%) of that side's trained range, so the
  per-side ranges from Calibrate are used (a stiff side still reaches full speed). f² keeps it gentle near rest.
- **Angles:** `mAngX`/`mAngY` (gyro along the learnt axes) are now pulled towards what gravity sees
  (`mouseGravAngle()`, complementary, 2 s, weighted by how far the axis is from "up"; only at about 1 g). So a nod or
  wrist roll doesn't drift; a head turn (about "up") gravity can't see. In Tilt, while still and inside the dead
  zone, those angles leak back to 0 (5 s), so drift settles while resting. This also steadies the live picture in Follow.
- **Rest** (`mouseRezero()`: angles 0, rest gravity = now): after Keep still, moving again after a pause, and MZERO
  (the page's Centre). So "pause, sit comfortably, move again" sets a new rest.
- The dead zone is a setting, not sized from the Keep still wobble (simpler; change if testing shows a need).
- 4 only keeps the curve, not a fixed speed. The page's picture shows the dead zone as a grey square.
- **To test:** head and wrist; the dead zone and speeds; whether a head turn drifts out of rest during use;
  4 only with someone with less control.

## Step 5 – true screen position (only if needed)

An absolute pointer report, USB first. It needs a changed report map, so paired devices would have to pair again,
and iPad support must be checked. Try it in MouseTest first.

## Step 6 – GAME mode (thumbstick, PC and Xbox)

A new mode (like MOUSE, hidden unless turned on): head or hand movement is a **thumbstick**, the switch is a button.
Goal: games on a **Windows PC** and on an **Xbox** (through the Xbox Adaptive Controller).

**Why movement suits a thumbstick:** a thumbstick reports a *position* (centre to fully pushed), like a head
angle; a mouse reports movement. So angle from rest → stick position, and back at rest = centred. No edge problem.
- **Calibrate is the same as MOUSE:** Keep still = centre; Right, Left, Down, Up = full push each way. Here the
  per-side ranges *are* used (dropped for MOUSE), so a stiff side still reaches full push.
- **Dead zone** around rest (sized from the Keep still wobble) and a **response curve** (fine near the middle,
  full at the comfortable limit). Settings: dead zone, curve, which stick (left / right), the switch's button.
- **Drift:** nod and wrist tilt are corrected from gravity (accelerometer). A head turn is gyro only (about
  0.07°/s measured), so: slowly re-centre while still inside the dead zone, plus Centre on a pause / switch hold.
- Mostly the same code as step 4 (tilt style), so do step 4 first.

**PC:** a USB HID joystick/gamepad works in Windows with no driver (DirectInput). Games that only take Xbox
controllers (XInput) need Steam Input or similar to map it. Bluetooth gamepad possible later, but it changes the
Bluetooth report map, so paired devices would pair again.

**Xbox:** an Xbox only accepts controllers with Microsoft's security chip, so not directly. The **Xbox Adaptive
Controller (XAC)** accepts USB HID joysticks on its USB ports: X,Y axes → left stick, Z,RZ → right stick, hat →
d-pad, buttons → XAC buttons. Copilot lets it share one player with another controller.
Known from open-source ESP32-S3 XAC joysticks (one is for M5Stack):
- the HID report must be laid out the way XAC expects (signed vs unsigned axes: unsigned has centre at 127,127);
- XAC firmware June 2024 or newer;
- XAC's USB ports give at most 100 mA unless the XAC has its 5 V 2 A supply (the stick charges from USB, so
  check the current, or run it on battery);
- **to check:** whether XAC accepts our composite USB device (keyboard + mouse + serial + gamepad) or needs a
  joystick-only USB device. If joystick-only, GAME mode restarts the stick's USB as a joystick (no setup page
  over USB while in GAME mode).

**Built 1 Oct 2026, to test** – straight into ChatterSwitch (no GameTest sketch). FW_API / PAGE_API = 9.
- Mode `M_GAME` (after MOUSE, blue), group `G_GAME`, `s_game` **Off** by default. `motionMode()` = MOUSE or GAME:
  they share the motion engine (`updateMouse`, calibration, `mAngX/Y`, pause, MZERO, the page's picture).
- USB: the core's `USBHIDGamepad` (X, Y, Z, Rz, Rx, Ry signed −127..127, hat, 32 buttons), added to the composite
  device (keyboard + mouse + serial) **only when `s_game` is on at start**; changing `s_game` restarts the stick
  (`gameRestartAt`). So nobody else gets an idle gamepad. No Bluetooth gamepad.
- `gameAxis()`: dead zone (`m_dead`, shared with Tilt) → 0..1 at `MS_TILT_FULL` (70%) of that side's range, then
  `powf(f, g_curve/10)` (*Response*: Straight 1.0, **Gentle** 1.5, Very gentle 2.2). `m_dirs` 4 only shared.
  *Stick* (`g_stick`) left = X/Y, right = Z/Rz. *Switch button* (`g_button`: A, B, X, Y, LB, RB = core buttons
  0, 1, 3, 4, 6, 7) held while the switch is. Pause centres the stick. The yaw leak to rest (inside the dead zone,
  still) always runs in GAME.
- Sent on change (button at once, stick at most every 10 ms). No hold to pause, clutch or freeze in GAME.
- **To test:** joy.cpl on Windows (axes, button, dead zone, curve); a game via Steam Input; then the XAC:
  whether it accepts the composite device and our report (signed axes), the 100 mA limit without its PSU,
  XAC firmware. If the XAC wants a joystick-only device, GAME would start USB as a gamepad only (no setup page
  over USB in GAME).

Sources: [ESP32 gamepad for XAC (esp32beans)](https://github.com/esp32beans/ESP32_gamepad),
[M5Stack USB joystick (esp32beans)](https://github.com/esp32beans/M5Stack_Touch_USB_Joystick),
[dinput_tinyusb for XAC](https://github.com/controllercustom/dinput_tinyusb),
[Arduino forum: joystick for XAC](https://forum.arduino.cc/t/joystick-for-xbox-adaptive-controller/1325039).

## Idea for later – head gestures (Quha Zono 2)

From the [Quha Zono 2 manual](https://www.zyteq.com.au/uploads/PDF/Access/Quha-Zono-2-User-Manual-v1.0-English.pdf):
every gesture starts with holding still for about a second, then a quick back-and-forth, e.g. **pause** = right,
left, right, left; **exit pause** = right, left. Gestures for scroll and centring too.
- The pointer does move during a gesture; back-and-forth ends where it started. We could also undo the wiggle:
  the stick knows the movement it sent since the still second, so once a gesture is recognised it sends the
  opposite and the pointer is back exactly.
- **Doubts:** quick back-and-forth needs good control (hard for many people with CP), and jerky movement could
  trigger it by accident. Hold to pause already covers pausing. So: optional and off by default, and only if
  users who can't use the switch to pause need it.

## Hardware and build notes

- StickS3 IMU: BMI270 (6-axis, no compass), so left/right is the gyro only. M5Unified `M5.Imu`, `cfg.internal_imu = true`.
- IDE Tools: ESP32S3 Dev Module, **USB CDC On Boot: Enabled**, USB Mode: USB-OTG (TinyUSB), 8MB, Huge APP, OPI PSRAM.
  The IDE keeps these between sketches. If they're wrong, the build fails or USB mouse/serial goes missing.
- Page and firmware go together: raise FW_API and PAGE_API when the serial protocol or INFO changes.

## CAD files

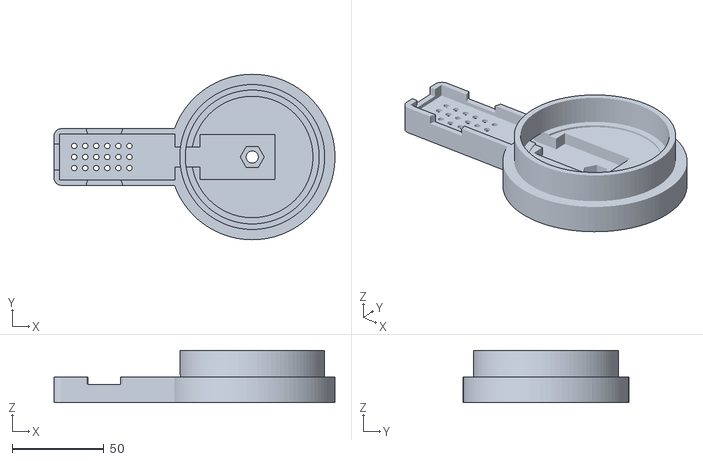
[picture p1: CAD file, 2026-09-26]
base.stl
152.8 x 90.0 x 28.5

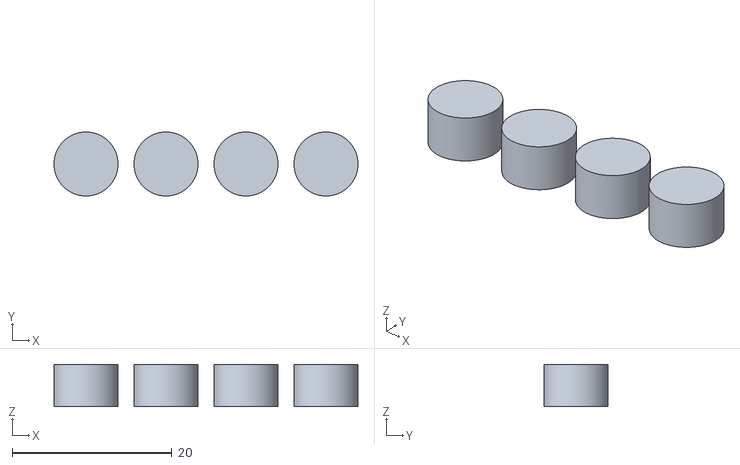
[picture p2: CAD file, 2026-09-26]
stem_test.stl
38.0 x 8.00 x 5.30

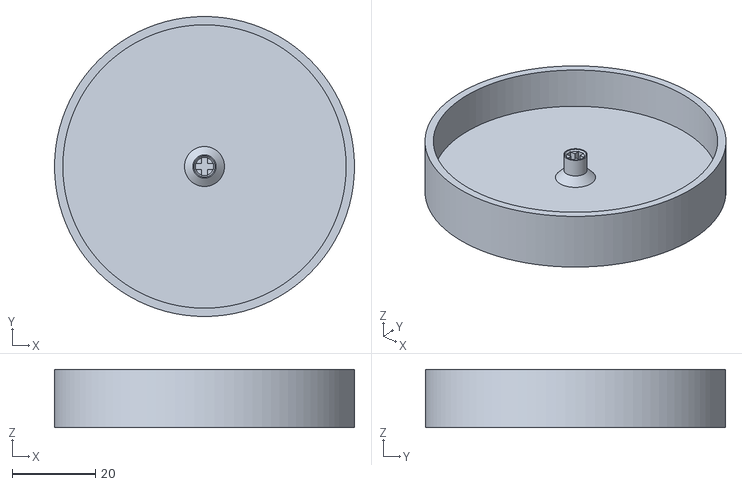
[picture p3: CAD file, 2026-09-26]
cap.stl
72.0 x 72.0 x 14.0

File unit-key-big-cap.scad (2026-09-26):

// =====================================================================
//  Guided big-cap accessibility switch for M5Stack Unit Key (U144)
// ---------------------------------------------------------------------
//  - Large press surface on the Unit Key's MX-style stem
//  - Printed collar guides the cap's skirt, so off-centre presses
//    still travel straight down (no tipping or binding)
//  - Stop ledge limits travel to protect the switch
//  - Pocket for the unit, exit slot for the Grove cable
//  - Captive 1/4"-20 nut for standard AT mounting arms / camera clamps
//  - Optional magnet pockets, symbol recess, tactile textures
//  - Optional side cradle for an M5StickS3 (talking switch / HID / IR brain)
//
//  PRINTING
//    Base: flat side down, no supports.
//    Cap:  printed top-face-down (already flipped in "all" / "cap"),
//          no supports. Translucent PETG lets the RGB LED glow through.
//
//  ASSEMBLY
//    1. Push a 1/4"-20 hex nut into the hex hole in the pocket floor.
//    2. Press-fit magnets (with a dab of glue) into the underside.
//    3. Drop the Unit Key into the pocket, cable out through the slot.
//    4. Plug the Grove cable into the StickS3 and seat it in the cradle,
//       screen up, Grove end towards the switch. Coil spare cable in the
//       bay (a 10cm Grove cable is tidier than the supplied 20cm one).
//    5. Remove the stock keycap and push the big cap onto the stem.
//
//  !! MEASURE YOUR UNIT FIRST and set the "Measure these" values. !!
//  Print "stem_test" first to dial in the stem fit (stem_tol).
// =====================================================================

/* [Part to render] */
part = "all"; // [all, base, cap, assembly, stem_test]

/* [Measure these on your unit] */
// Unit housing length (mm)
unit_l = 40;
// Unit housing width (mm)
unit_w = 24;
// Height from the bottom of the unit to the top of the MX stem, stock keycap REMOVED (mm)
stem_top_h = 18;
// Offset of the switch centre from the unit's centre along its length (+ = away from the Grove connector end)
key_x_offset = 8;
// Clearance around the unit in its pocket (mm)
unit_clearance = 0.3;

/* [Cap] */
// Diameter of the press surface (mm)
cap_d = 72;
// Thickness of the top plate (mm)
top_t = 4;
// Skirt wall thickness (mm)
skirt_t = 2;
// Radial gap between skirt and collar (mm). Increase if it rubs.
fit_clearance = 0.4;
// How far the skirt sits inside the collar at rest (mm). More = steadier.
engage = 10;
// Maximum travel before the skirt hits the stop ledge (mm). Blue switches actuate ~2mm and bottom out ~4mm.
stop_travel = 3.5;

/* [Stem socket] */
// Length of each arm of the MX cross (mm)
cross_len = 4.1;
// Width of the MX cross arms (mm)
cross_w = 1.3;
// Extra clearance on the cross (mm). Tune with the stem_test part.
stem_tol = 0.1;
// Depth of the stem socket (mm)
socket_depth = 3.8;
// Diameter of the boss around the socket (mm)
boss_d = 5.6;

/* [Top surface] */
// Shallow recess for a paper symbol under a clear disc
symbol_recess = true;
// Symbol recess diameter (mm)
symbol_d = 50;
// Symbol recess depth (mm): paper + ~0.5mm clear acetate/PETG disc
symbol_depth = 1.2;
// Tactile texture (applied outside the symbol area)
texture = "none"; // [none, grooves, dimples]

/* [Base] */
// Overall base diameter (mm). Wider = more stable.
base_d = 90;
// Solid floor under the unit pocket (mm). Must be > nut_t + ~2.
floor_t = 8;
// How deep the unit sits in the base (mm)
pocket_depth = 6;
// Collar wall thickness (mm)
wall_t = 3;
// Grove cable slot width (mm)
cable_w = 11;
// Grove cable slot height (mm)
cable_h = 7;
// Captive 1/4"-20 nut for mounting arms
nut_trap = true;
// Nut across-flats (mm). 1/4"-20 hex nut = 11.11
nut_af = 11.11;
// Nut thickness allowance (mm)
nut_t = 5.8;
// Clearance hole for the 1/4" stud (mm)
bolt_d = 6.6;
// Magnet pockets on the underside
magnets = true;
// Magnet diameter (mm)
magnet_d = 10;
// Magnet thickness (mm)
magnet_t = 3;
// Magnet pocket clearance (mm)
magnet_tol = 0.2;

/* [StickS3 cradle] */
// Add a side cradle that holds an M5StickS3, screen up, Grove end facing the switch
stick_cradle = true;
// StickS3 length (mm)
stick_l = 48;
// StickS3 width (mm)
stick_w = 24;
// StickS3 thickness (mm)
stick_t = 15;
// Clearance around the StickS3 (mm)
stick_clearance = 0.4;
// How deep the StickS3 sits in the cradle (mm). Keep low so side buttons stay reachable.
stick_pocket_depth = 6;
// Space between the cradle and the switch for the Grove plug and spare cable (mm)
cable_bay_l = 14;
// Cradle wall thickness (mm)
cradle_wall = 3;
// Holes under the StickS3 so its speaker is not muffled
speaker_holes = true;

/* [Hidden] */
$fn = 96;
eps = 0.01;

// ---------------------------------------------------------------------
//  Derived geometry (world Z = 0 at the bottom of the base)
// ---------------------------------------------------------------------
cap_r          = cap_d / 2;
collar_ir      = cap_r + fit_clearance;
collar_or      = collar_ir + wall_t;
base_h         = floor_t + pocket_depth;
stem_top_z     = floor_t + stem_top_h;
boss_bottom_z  = stem_top_z - socket_depth;   // underside of cap boss at rest
skirt_bottom_z = base_h + stop_travel + 1;    // 1mm spare gap at full stop
plate_under_z  = skirt_bottom_z + engage;     // underside of top plate at rest
boss_len       = plate_under_z - boss_bottom_z;
stop_z         = skirt_bottom_z - stop_travel; // top of the stop ledge
ledge_ir       = cap_r - skirt_t - 1;
unit_corner_r  = sqrt(pow(unit_l/2 + abs(key_x_offset) + unit_clearance, 2)
                    + pow(unit_w/2 + unit_clearance, 2));

// StickS3 cradle layout (along -X, the same side as the cable slot)
stick_pl       = stick_l + 2 * stick_clearance;  // pocket length
stick_pw       = stick_w + 2 * stick_clearance;  // pocket width
cradle_in_x    = -base_d / 2 + 3;                // inner end of the cable bay
stick_in_x     = cradle_in_x - cable_bay_l;      // StickS3 end nearest the switch
stick_out_x    = stick_in_x - stick_pl;          // StickS3 outer (USB-C) end
cradle_out_x   = stick_out_x - cradle_wall;
cradle_floor_z = base_h - stick_pocket_depth;
cradle_half_w  = stick_pw / 2 + cradle_wall;

assert(!stick_cradle || cradle_in_x < -collar_or,
       "Cable bay cuts into the collar: increase base_d.");
assert(!stick_cradle || cradle_floor_z >= 2,
       "Cradle floor too thin: reduce stick_pocket_depth.");

assert(boss_len >= socket_depth + 0.5,
       "Stem top is above the cap plate: increase engage or reduce pocket_depth.");
assert(unit_corner_r + 0.5 < ledge_ir,
       "Unit does not fit inside the skirt: increase cap_d.");
assert(collar_or < base_d / 2,
       "Collar is wider than the base: increase base_d.");
assert(!nut_trap || floor_t >= nut_t + 1.5,
       "Floor too thin for the nut: increase floor_t.");

echo(str("Base height: ", base_h, " mm, collar top: ", plate_under_z, " mm"));
echo(str("Cap stands ", top_t, " mm proud of the collar at rest, ",
         top_t - stop_travel, " mm at full press"));
echo(str("Max 1/4\" stud length into base: ~", floor_t, " mm"));

// ---------------------------------------------------------------------
//  Modules
// ---------------------------------------------------------------------
module mx_socket() {
    l = cross_len + 2 * stem_tol;
    w = cross_w + 2 * stem_tol;
    linear_extrude(socket_depth + eps) {
        square([l, w], center = true);
        square([w, l], center = true);
    }
    // Lead-in chamfer so the cap finds the stem easily
    translate([0, 0, -eps]) cylinder(d1 = l + 0.8, d2 = l, h = 0.4);
}

module texture_cuts(z_top) {
    r_in = symbol_recess ? symbol_d / 2 + 4 : 6;
    r_out = cap_r - 4;
    if (texture == "grooves") {
        for (r = [r_in : 6 : r_out])
            translate([0, 0, z_top - 1])
                difference() {
                    cylinder(r = r + 0.8, h = 1 + eps);
                    translate([0, 0, -1]) cylinder(r = r - 0.8, h = 3);
                }
    }
    if (texture == "dimples") {
        for (x = [-r_out : 7 : r_out], y = [-r_out : 7 : r_out]) {
            d = sqrt(x * x + y * y);
            if (d >= r_in && d <= r_out)
                translate([x, y, z_top + 0.8]) sphere(d = 4, $fn = 24);
        }
    }
}
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

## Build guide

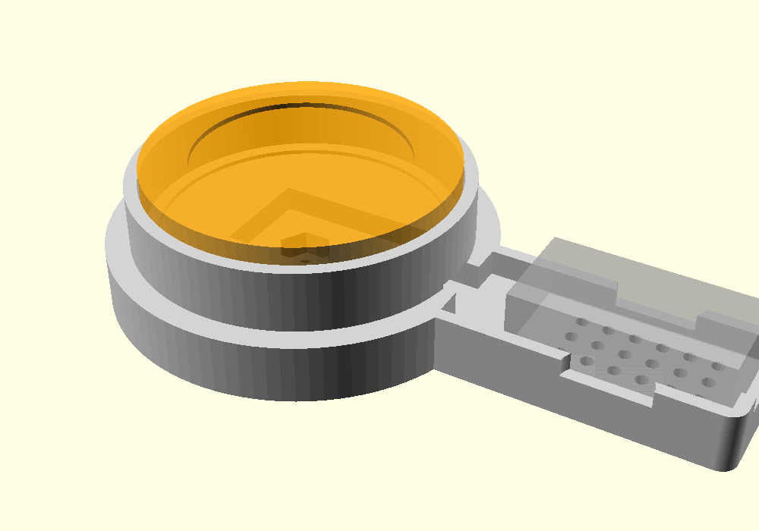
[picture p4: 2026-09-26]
assembly.png

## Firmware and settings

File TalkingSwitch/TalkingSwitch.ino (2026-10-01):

// =====================================================================
//  ChatterSwitch - M5StickS3 + M5Stack Unit Key accessibility switch
// ---------------------------------------------------------------------
//  One big switch, four jobs (modes), named after what they hold:
//    QUICK     The 4 Quick messages. "Messages" setting:
//                Staff pick - plays the selected one (BIGmack style). Play
//                  style: Tap / Hold to play / Latch. With Tap, keep holding
//                  the switch to move on to the next Quick message.
//                Student chooses - by scanning (below), with QUICK's own
//                  "Choosing": Press twice / Hold & release / Count presses -
//                  press 1 to 4 times quickly for message 1 to 4; after the
//                  "Press gap" with no press, that message plays.
//    TOPICS    The 4 Topics of 4 messages, by scanning. Choose from:
//                One topic - the messages in the topic staff selected;
//                All topics - the topics first, then that topic's messages
//                  plus "Back". "Offer Quick / Control / My device" add those
//                  as choices next to the topics: the Quick messages and the
//                  IR codes are offered like a topic's messages, and My
//                  device changes to KEYBOARD for the student's AAC device.
//    KEYBOARD  Acts as a USB or Bluetooth keyboard key, e.g. Space/Enter
//              for Grid 3 or Mind Express switch access, or the left mouse
//              button (Left click; it's a keyboard and mouse in one). Key goes down on
//              press and up on release, so dwell and hold-to-scan settings
//              in the AAC software still work. When a computer is using it
//              as a USB keyboard, keys go over USB only; otherwise they go
//              over Bluetooth. (Never both, so no double presses.)
//              "No USB" setting: Bluetooth, or a backup mode - with no USB
//              connection (the AAC device isn't there) it changes to QUICK
//              or TOPICS by itself, with Bluetooth off, and comes back to
//              KEYBOARD when USB is connected again.
//    CONTROL   Sends the selected learned infrared (IR) code (TV, fibre
//              optics, bubble tube), and plays that code's own sound if it
//              has one (e.g. "Bubbles!"). "IR codes" setting: Staff pick /
//              Repeat while held / Student scans (the student chooses).
//    MOUSE     (SETTINGS "MOUSE mode: Off" hides it) The stick's motion
//              sensor moves the pointer - worn on the head or a hand - and
//              the big switch clicks; optional dwell click. Over USB or
//              Bluetooth like KEYBOARD. B steps to "Calibrate" (learns the
//              user's own movements: rest, right, left, down, up); hold A
//              pauses; holding the switch can pause too ("Hold to pause").
//  Scanning: the switch offers the choices one at a time (LED colour, name
//  on screen, a quiet spoken prompt) and the student picks one, which then
//  plays. Choosing: Press twice - a press starts, the next chooses;
//  Hold & release - hold to step through, let go to choose.
//
//  Each Quick message, topic message and IR code is up to 5 s, with an
//  optional name. The setup page turns the names into the short spoken
//  prompts used when scanning.
//    SETTINGS  General settings (volume, modes, press timing, the ToF sensor,
//              screen, power, Bluetooth, About). "Modes" can turn KEYBOARD
//              and/or CONTROL off for a talking-only switch: A then skips them
//              (key and codes are kept).
//              Each mode has its own settings too, as the last item B steps to.
//              The big switch keeps doing the previous mode's job.
//
//  Staff controls on the StickS3 - one rule everywhere (the bottom line of
//  the screen always shows what they do; a hold is 0.6 s; when the screen is
//  off, the first press only wakes it - when it's just dim, presses work):
//    A click .... next mode (in a mode's settings, an open topic, About or
//                 Sensor test: close it)
//    B click .... next: Quick message / topic / key / IR code / Calibrate, then the
//                 mode's "Settings" item; in settings, the next setting
//    Hold A ..... do it: QUICK record the message (one already there: hold
//                 again to replace it), CONTROL learn the code,
//                 TOPICS open the topic (B then steps through its messages,
//                 A closes it), MOUSE pause / move (on "Calibrate": start
//                 it), on "Settings" open them, in settings change
//                 the value (or open About / Sensor test)
//    Hold B ..... hear it: QUICK the message, an open topic's message,
//                 CONTROL the code's sound; in settings, back a value
//                 (B itself is silent, to save battery)
//
//  Power saving: the screen dims, then switches off, when idle. Bluetooth
//  only runs in KEYBOARD and MOUSE modes. On battery, after the "Sleep after"
//  time with no presses, it sleeps (except in KEYBOARD or MOUSE mode or with
//  the ToF sensor, which can't wake it); the
//  big switch still works and wakes it. Optionally it can also power off
//  completely after a longer time (press the power button to restart).
//
//  Switch access settings (press must last, ignore repeats) help students with
//  tremor or accidental presses. Every student activation is logged
//  on the USB serial port as "press,<ms since boot>,<mode>".
//
//  Hardware
//    - M5StickS3 (ESP32-S3), M5Unified library
//    - M5Stack Unit Key (U144) on the StickS3's Grove port
//      GPIO10 -> key (PIN_KEY): the yellow wire on a standard Grove cable
//      GPIO9  -> LED (PIN_LED): the white wire (colours can vary between cables)
//      If the key does nothing, swap PIN_KEY and PIN_LED.
//    - A standard 3.5mm AT switch can be wired to PIN_KEY and GND
//      instead of (or alongside) the Unit Key.
//    - Or an M5Stack Unit ToF4M distance sensor (VL53L1X) on the Grove port,
//      as a touch-free switch: found by itself at start-up (not together
//      with the Unit Key or a jack switch - they share the Grove pins). Its
//      settings appear in SETTINGS; "Sensor test" shows a live graph.
//      Needs the "VL53L1X" library by Pololu.
//
//  Arduino IDE settings: sketch.yaml / README.md.
// =====================================================================

#include <M5Unified.h>
#include <LittleFS.h>
#include <Preferences.h>
#include <BLEDevice.h>
#include <BLEServer.h>
#include <BLEHIDDevice.h>
#include <esp_sleep.h>
#include <driver/gpio.h>
#include <esp_mac.h>
#include <Wire.h>
#include <VL53L1X.h>
#if defined(CONFIG_NIMBLE_ENABLED)
#include "host/ble_hs.h"
#else
#include <BLESecurity.h>
#endif

#if ARDUINO_USB_MODE == 0  // "USB Mode: USB-OTG (TinyUSB)" selected
#include "USB.h"
#include "USBHIDKeyboard.h"
#include "USBHIDMouse.h"
#include "USBHIDGamepad.h"
#define HAS_USB_HID 1
USBHIDKeyboard UsbKeyboard;
USBHIDMouse UsbMouse;
USBHIDGamepad UsbGamepad;  // only started with GAME mode on (see setup)
#if !ARDUINO_USB_CDC_ON_BOOT
#error "Set Tools > USB CDC On Boot: Enabled - the setup page talks to the switch over it"
#endif
#else
#define HAS_USB_HID 0
#define MOUSE_LEFT  0x01
#define MOUSE_RIGHT 0x02
#endif

// ToF sensor settings that are the same for everyone
static const int SENSE_MIN_MM = 40;        // closer than this isn't reliable: counts as pressed
static const int SENSE_LOST_LET_GO = 10;   // while pressed, this many unreliable readings in a row (~150 ms) let go
static const int SENSE_GRAPH_W = 224;      // Sensor test graph: one reading per pixel (~3.5 s)

// Firmware version. FW_API goes up whenever the setup page needs to change
// with it (the page shows a warning if the numbers don't match).
static const char* FW_VERSION = "1 Oct 2026";
static const int   FW_API     = 9;

// ---------------------------------------------------------------------
//  Settings you may want to change
// ---------------------------------------------------------------------
static const int PIN_KEY   = 10;   // Unit Key switch signal (Grove)
static const int PIN_LED   = 9;    // Unit Key SK6812 LED data (Grove)
static const int PIN_IR_TX = 46;   // StickS3 IR transmitter
static const int PIN_IR_RX = 42;   // StickS3 IR receiver

static const uint32_t DEBOUNCE_MS = 25;    // ignore contact bounce
static const uint32_t LONG_REPEAT_MS = 2000; // QUICK long press: keep moving on every this long while held

static const uint32_t SAMPLE_RATE = 16000; // recording sample rate (Hz)
static const uint32_t MAX_SECONDS = 5;     // longest message / IR code sound
static const uint32_t PROMPT_SECONDS = 2;  // longest scanning prompt
static const int      NUM_QUICK   = 4;     // Quick messages (QUICK)
static const int      NUM_TOPICS  = 4;     // Topics (TOPICS)...
static const int      PER_TOPIC   = 4;     // ...of up to 4 messages
static const int      NUM_SLOTS   = 4;     // IR codes (and the 4 item colours)
// Sound numbers (the setup page uses the same ones):
//   0-3 Quick messages, 4-19 topic messages (topic t, item k = 4 + t*4 + k),
//   20-23 IR codes' sounds, 24-39 topic message prompts, 40-43 topic prompts,
//   44-47 IR code prompts, 48 the "Back" prompt, 49-52 Quick message prompts,
//   53 the "Stop" prompt, 54 "Control", 55 "My device", 56 "Quick"
static const int SND_TOPIC = NUM_QUICK, SND_IR = SND_TOPIC + NUM_TOPICS * PER_TOPIC, SND_PMSG = SND_IR + NUM_SLOTS,
                 SND_PTOPIC = SND_PMSG + NUM_TOPICS * PER_TOPIC, SND_PIR = SND_PTOPIC + NUM_TOPICS,
                 SND_PBACK = SND_PIR + NUM_SLOTS, SND_PQUICK = SND_PBACK + 1,
                 SND_PSTOP = SND_PQUICK + NUM_QUICK, SND_PIRMENU = SND_PSTOP + 1, SND_PTALKER = SND_PIRMENU + 1,
                 SND_PQMENU = SND_PTALKER + 1, NUM_SOUNDS = SND_PQMENU + 1;
// Name numbers: 0-3 Quick, 4-19 topic messages, 20-23 IR codes (as sounds), 24-27 topics
static const int NAME_TOPIC = SND_PMSG, NUM_NAMES = NAME_TOPIC + NUM_TOPICS;
static const uint8_t  MIC_PGA     = 8;     // mic analogue gain, 3dB steps (0-10). Lower if loud voices distort

static const char*    BLE_NAME      = "ChatterSwitch";  // default Bluetooth name; the last 4 characters of the
                                                        // stick's address are added, e.g. "ChatterSwitch 7B70"
static const uint8_t  VOLUMES[]     = {128, 180, 220, 255}; // output power is volume squared: ~25/50/75/100%
static const uint8_t  SPK_GAIN      = 8;   // speaker magnification: 8 = volume 4 is exactly full scale
                                           // (M5Unified's StickS3 default of 1 is 18dB quieter)
static const int      IR_REPEATS    = 2;   // extra copies of the IR code (helps at the edge of range)
static const float    IR_DUTY       = 0.5f; // carrier duty: 0.5 = most energy per pulse (remotes often use 0.33)
static const uint32_t IR_REPEAT_MS  = 110; // CONTROL, Repeat held: resend this often while held
static const uint32_t STATUS_MS     = 2500; // how long status messages stay on screen

// Power saving
// normal screen brightness: the "Brightness" setting (lower saves battery)
static const uint8_t  SCREEN_DIMMED = 16;     // faint glow when idle
static const uint32_t SCREEN_DIM_MS = 30000;  // dim the screen after this long without a staff button press
static const uint32_t SCREEN_OFF_MS = 120000; // then switch it off completely
static const uint32_t SETTINGS_EXIT_MS = 30000; // SETTINGS goes back to the previous mode after this long untouched
static const uint32_t BACKUP_MS = 10000;        // KEYBOARD with no USB this long: change to the backup mode
static const int      LOW_BATTERY   = 15;     // warn below this battery %

// ---------------------------------------------------------------------
//  Modes and keys
// ---------------------------------------------------------------------
enum Mode : uint8_t { M_SPEAK, M_CHOOSE, M_KEYBOARD, M_IR, M_MOUSE, M_GAME, M_SETTINGS, M_COUNT };
static const char* MODE_NAMES[M_COUNT] = {"QUICK", "TOPICS", "KEYBOARD", "CONTROL", "MOUSE", "GAME", "SETTINGS"};
// Mode colours for the switch LED (dim idle glow)
static const uint8_t MODE_RGB[M_COUNT][3] = {
  {0, 40, 0}, {0, 30, 40}, {30, 0, 40}, {40, 20, 0}, {40, 0, 20}, {0, 10, 40}, {0, 0, 0}
};
// QUICK, TOPICS and IR: the LED shows which message / topic / code it's on
static const uint8_t SLOT_RGB[NUM_SLOTS][3] = {{0, 40, 0}, {0, 25, 40}, {30, 0, 40}, {40, 20, 0}};
// Mode colours for the screen header, and whether it needs dark text
static const uint8_t SCREEN_RGB[M_COUNT][3] = {
  {0, 160, 70}, {0, 140, 160}, {140, 60, 220}, {240, 130, 0}, {210, 40, 110}, {30, 90, 220}, {90, 90, 90}
};
static const bool HEADER_DARK_TEXT[M_COUNT] = {false, false, false, true, false, false, false};

enum KbOut : uint8_t { OUT_NONE, OUT_BLE, OUT_USB };  // where keyboard presses go
enum MouseCal : uint8_t { MC_NONE, MC_REST, MC_RIGHT, MC_LEFT, MC_DOWN, MC_UP };  // MOUSE calibration step
enum PlayStyle : uint8_t { PLAY_TAP, PLAY_HOLD, PLAY_LATCH };
// A choice offered while scanning (declared here, before any function)
enum ScanKind : uint8_t { SK_GROUP, SK_MSG, SK_BACK, SK_IR, SK_STOP, SK_IRMENU, SK_TALKER, SK_QMENU };
struct ScanItem { uint8_t kind, idx; };

enum Arrow : uint8_t { A_NONE, A_UP, A_DOWN, A_LEFT, A_RIGHT };
struct KeyDef { const char* name; uint8_t usage; Arrow arrow; };
static const uint8_t USAGE_LCLICK = 0xF0;  // not a real key (0xE8-0xFF are unused): the left mouse button
static const KeyDef KEYS[] = {
  {"SPACE", 0x2C, A_NONE}, {"ENTER", 0x28, A_NONE},
  {"UP",    0x52, A_UP},   {"DOWN",  0x51, A_DOWN},
  {"LEFT",  0x50, A_LEFT}, {"RIGHT", 0x4F, A_RIGHT},
  {"LEFT CLICK", USAGE_LCLICK, A_NONE}
};
static const int NUM_KEYS = sizeof(KEYS) / sizeof(KEYS[0]);

// ---------------------------------------------------------------------
//  Staff settings - changed in SETTINGS mode on the StickS3
//  and remembered after power-off. Each has a fixed list of choices.
// ---------------------------------------------------------------------
enum SettingId : uint8_t {
  S_VOLUME, S_MODES, S_MOUSE_ON, S_GAME_ON, S_SPEAK_CHOOSE, S_QUICK_HOW, S_GAP, S_PLAY, S_HOLD, S_CHOOSE_FROM, S_OFFER_QUICK, S_OFFER_CONTROL, S_OFFER_DEVICE, S_IR_CHOOSE, S_ACCESS, S_SCAN_SPEED, S_SCAN_ROUNDS, S_STOP,
  S_KEY_ACTION, S_PRESS_SOUND, S_NO_USB,
  S_M_STYLE, S_M_SPEED, S_M_SPEEDY, S_M_ACCEL, S_M_TSPEED, S_M_DEAD, S_M_DIRS, S_M_STEADY, S_M_SMOOTH, S_M_DWELL, S_M_AREA, S_M_SWITCH, S_M_HOLD, S_M_CLUTCH, S_M_FREEZE, S_M_DOUBLE,
  S_G_STICK, S_G_BUTTON, S_G_CURVE,
  S_ACCEPT, S_LOCKOUT, S_SENSE_MODE, S_SENSE_LINE, S_SENSE_MOVE, S_SETTLE, S_FOLLOW, S_BEYOND, S_SENSE_TEST, S_BRIGHT, S_WAKE, S_SLEEP, S_AUTOOFF, S_LOUD, S_FORGET, S_ABOUT,
  S_COUNT
};
// Which settings screens a setting appears on (a setting can be on several)
enum SettingGroup : uint8_t { G_GENERAL = 1, G_SPEAK = 2, G_CHOOSE = 4, G_KEYBOARD = 8, G_IR = 16, G_MOUSE = 32, G_GAME = 64 };
struct Setting {
  const char* name;       // shown on screen
  const char* key;        // Preferences key (nullptr = an action, not a stored value)
  uint8_t count, def;     // number of choices, default choice
  uint32_t values[8];
  const char* labels[8];
  uint8_t groups;         // SettingGroup bits
};
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
void loop() {
  M5.update();
  pollSensor();
  pollStudentSwitch();
  pollStaffButtons();
  pollSerial();

  uint32_t now = millis();
  if (ledFlashUntil && now >= ledFlashUntil) { ledFlashUntil = 0; ledIdle(); }
  if (statusMsg.length() && now >= statusUntil) { statusMsg = ""; needRedraw = true; }

  checkVbus(now);
  static bool lastUsb = false;
  bool u = usbHostActive();
  if (u != lastUsb) { lastUsb = u; needRedraw = true; }

  static uint32_t lastRefresh = 0;
  if (now - lastRefresh > 5000) { lastRefresh = now; readBattery(); }
  if (forgetConfirmUntil && now >= forgetConfirmUntil) { forgetConfirmUntil = 0; needRedraw = true; }
  if (recordConfirmUntil && now >= recordConfirmUntil) { recordConfirmUntil = 0; needRedraw = true; }
  if (sensorTest && now - lastInteraction > 300000) { sensorTest = false; needRedraw = true; }
  if (aboutOpen && now - lastInteraction > SETTINGS_EXIT_MS) { aboutOpen = false; needRedraw = true; }
  if (inSettings() && !sensorTest && now - lastInteraction > SETTINGS_EXIT_MS) { mode = prevMode; ledIdle(); needRedraw = true; }
  if ((modeSettingsOpen || gateShown || topicOpen || mouseItem) && !sensorTest && now - lastInteraction > SETTINGS_EXIT_MS) {
    modeSettingsOpen = gateShown = topicOpen = false;
    mouseItem = 0;
    needRedraw = true;
  }
  updateScan(now);
  if (pressTally && (int32_t)(now - tallyEnds) >= 0) {  // Count presses: the gap ended the count
    int m = pressTally - 1;
    pressTally = 0;
    if (studentMode() != M_SPEAK || !countPresses()) {}  // mode changed meanwhile: nothing
    else if (slotLen[m]) { slot = m; saveSettings(); playSlot(m); }
    else beep(300, 150);
    ledIdle();
    needRedraw = true;
  }
  manageBackup(now);
  updateMouse(now);
  manageBle(now);
  managePower(now);
  if (needRedraw && scr != SCR_OFF) drawScreen();
  delay(2);
}

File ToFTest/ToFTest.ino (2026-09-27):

// =====================================================================
//  ToFTest - try the M5Stack Unit ToF4M (VL53L1X) as a touch-free switch
// ---------------------------------------------------------------------
//  A separate test sketch (not the ChatterSwitch firmware): plug the ToF4M
//  into the StickS3's Grove port instead of the Unit Key (not both, and not
//  a switch on the mono jack - they share the Grove pins) and upload this.
//
//  Two ways to "press":
//    LINE ... closer than a set distance (5-50 cm). One reading inside
//             counts; two readings back out past a small margin (10% of
//             the distance, at least 4 mm) let go.
//    MOVE ... a movement of a set size (5-30 mm) towards the sensor from
//             where the hand or finger is resting. The resting distance
//             is learnt while not pressed ("Follow" speed), so it copes
//             with the student shifting position - for small movements
//             like a finger. After it has been pressed for the "Settle"
//             time, where the finger is becomes the new resting place and
//             it lets go (without another press), so a finger that relaxes
//             closer doesn't leave it stuck pressed.
//  The screen shows the distance, a scrolling graph of the last few
//  seconds (it zooms to fit, so small movements show) with the trigger
//  line in yellow, and how many presses it has counted. The header turns
//  green while "pressed", with a beep for each press.
//
//    A click .... next size (distance in LINE, movement in MOVE)
//    Hold A ..... LINE / MOVE
//    B click .... reset the count, the graph and the "lost" figure
//    Hold B ..... settings: B next, hold A change, A close
//
//  Settings: Mode, Distance / Movement, Settle, Follow, Ignore beyond,
//  Field of view, Smoothing, Too close, Range (see SETTINGS below).
//
//  Tips: the sensor isn't reliable closer than about 4 cm, and it sees a
//  cone about 27 degrees wide ("Field of view" narrows it) - so a finger
//  works best 5-10 cm away, where it fills more of the view.
//
//  Readings also go to the USB serial port (115200) for the Arduino IDE's
//  Serial Plotter, as  distance_cm:<cm>,trigger_cm:<cm>,pressed:<0 or 10>
//  (open the plotter after the stick has started - its USB port disappears
//  while it restarts).
//
//  Needs the "VL53L1X" library by Pololu (Arduino Library Manager).
//  Board settings: sketch.yaml (the same as the ChatterSwitch firmware).
// =====================================================================

#include <M5Unified.h>
#include <Wire.h>
#include <VL53L1X.h>

VL53L1X tof;
M5Canvas canvas(&M5.Display);

// ---------------------------------------------------------------------
//  Settings (changed on the stick: hold B)
// ---------------------------------------------------------------------
enum SettingId { T_MODE, T_LINE, T_MOVE, T_SETTLE, T_FOLLOW, T_BEYOND, T_FOV, T_SMOOTH, T_CLOSE, T_RANGE, T_COUNT };
struct Setting { const char* name; uint8_t count, cur; int values[8]; const char* labels[8]; };
Setting SETTINGS[T_COUNT] = {
  {"Mode",          2, 1, {0, 1}, {"LINE", "MOVE"}},
  // LINE: press closer than this (mm)
  {"Distance",      8, 3, {50, 60, 80, 100, 150, 200, 300, 500}, {"5 cm", "6 cm", "8 cm", "10 cm", "15 cm", "20 cm", "30 cm", "50 cm"}},
  // MOVE: press on a movement this big towards the sensor (mm)
  {"Movement",      6, 1, {5, 8, 10, 15, 20, 30}, {"5 mm", "8 mm", "10 mm", "15 mm", "20 mm", "30 mm"}},
  // MOVE: pressed this long -> where the hand is becomes the resting place (ms)
  {"Settle",        5, 2, {0, 1000, 2000, 3000, 5000}, {"Off", "1 s", "2 s", "3 s", "5 s"}},
  // MOVE: how quickly the resting distance follows drift (per 1000 readings)
  {"Follow",        3, 1, {8, 20, 50}, {"Slow", "Medium", "Fast"}},
  // anything further than this counts as nothing there (mm, 0 = off)
  {"Ignore beyond", 4, 0, {0, 200, 300, 500}, {"Off", "20 cm", "30 cm", "50 cm"}},
  // the sensor's view: how many of its 16x16 zones it uses
  {"Field of view", 3, 0, {16, 10, 6}, {"Wide", "Medium", "Narrow"}},
  // take the middle of the last 3 readings (removes single spikes, ~30 ms later)
  {"Smoothing",     2, 0, {1, 3}, {"Off", "3 readings"}},
  // closer than the sensor can measure (about 4 cm): pressed, or nothing there
  {"Too close",     2, 0, {1, 0}, {"Pressed", "Nothing"}},
  // Short: up to ~1.3 m, faster (~65 a second), better in sunlight. Long: ~4 m, slower
  {"Range",         2, 0, {0, 1}, {"Short", "Long"}},
};
int val(SettingId i) { return SETTINGS[i].values[SETTINGS[i].cur]; }
const char* label(SettingId i) { return SETTINGS[i].labels[SETTINGS[i].cur]; }
bool moveMode() { return val(T_MODE) == 1; }
bool shown(int i) {  // settings that do something with the current choices
  if (i == T_LINE) return !moveMode();
  if (i == T_MOVE || i == T_SETTLE || i == T_FOLLOW) return moveMode();
  return true;
}

static const int PRESS_READINGS = 1;    // readings in a row past the line to press (1 catches a quick wave)
static const int RELEASE_READINGS = 2;  // ...and back to let go (so one stray reading can't)
static const int LOST_LET_GO = 10;      // while pressed, this many unreliable readings in a row (~150 ms) let go
static const int MIN_MM = 40;           // closer than this isn't reliable ("Too close")
static const int GRAPH_W = 224;         // readings shown, one per pixel (~3.5-4.5 s)
static const int GRAPH_MIN_SPAN = 30;   // the graph shows at least this many mm top to bottom

// ---------------------------------------------------------------------
//  State
// ---------------------------------------------------------------------
bool settingsOpen = false;
int settingIdx = 0;
bool sensorOk = false;
int distMm = -1;             // latest reading used (-1 = nothing there / unreliable)
bool tooClose = false;       // ...closer than the sensor can measure
float restMm = -1;           // MOVE: the resting distance (-1 = not learnt yet)
bool pressed = false;
int streak = 0;              // readings in a row on the other side of the line
uint32_t pressedAt = 0;      // MOVE, Settle: when the press started...
float holdAvg = -1;          // ...and where the hand has been lately (a short average)
int lostRun = 0;             // unreliable readings in a row
int recent[3], recentN = 0;  // Smoothing: the last 3 readings
uint32_t presses = 0;
uint32_t readings = 0, lost = 0, rateCount = 0, rateStart = 0;
float rateHz = 0;
int16_t history[GRAPH_W];      // mm, -1 = none
int16_t historyLine[GRAPH_W];  // the trigger line at that reading
bool historyPressed[GRAPH_W];
int historyPos = 0;
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

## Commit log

2026-09-26 Talking Switch: firmware, USB setup page with typed speech, 3D printed case
    M5StickS3 + M5Stack Unit Key accessibility switch: talking switch,
    step-by-step, USB/Bluetooth keyboard key and IR remote. The setup page
    (docs/, for GitHub Pages) configures it over USB with Web Serial and can
    make messages from typed text using Piper voices served from the site.
    [base.stl, cap.stl, partitions.csv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]
2026-09-26 Simpler setup page with tabs; fix quiet speaker
    Setup page: mode and volume at the top, then Messages / IR remote /
    Keyboard / Settings tabs. Each message has one Change panel with
    Record, Type words or Upload file, then Listen and Save. IR codes have
    their own tab. Settings are grouped with a short explanation each.
    Firmware: M5Unified sets the StickS3 speaker magnification to 1, which
    plays full-scale sound at about 12% (-18dB). Set it to 8 so volume 4 is
    full scale. Recordings (on the switch and from the page) now drop bass
    below ~200Hz that the small speaker can't reproduce, and the page's
    default loudness matches the switch's.
    [TalkingSwitch.ino]
2026-09-26 Separate IR codes with optional sounds; remove STEPS and SPEAK+IR
    Messages and IR codes are now separate: 4 messages for SPEAK and 4 IR
    codes for IR, each with its own name and its own selected item. Each IR
    code can have an optional sound (recorded, typed or uploaded on the IR
    remote tab) that the switch says as it sends the code, which replaces
    the SPEAK+IR mode. STEPS is removed. Modes are now SPEAK, KEYBOARD, IR
    and SETTINGS; a saved mode from older firmware is converted.
    [TalkingSwitch.ino]
2026-09-26 Scanning: choose a message or IR code with one switch
    New Play style "Scan": a press starts offering each message (SPEAK) or
    IR code (IR) in turn - LED colour, name on screen and a quiet spoken
    prompt - and the next press chooses it. Scan speed and rounds are new
    settings. Prompts are short sounds stored separately (up to 3 s each);
    the setup page makes them automatically from the names with the chosen
    voice, and when Scan is switched on it makes any that are missing.
    [TalkingSwitch.ino]
2026-09-26 One voice per switch for typed messages and scanning prompts
    The voice and speed are chosen once, on the Settings tab, and stored on
    the switch (new VOICE command), so every computer uses the same voice.
    Changing it remakes all the scanning prompts. The per-message voice
    choice in the Type words panel is gone; it shows the switch's voice.
2026-09-26 CHOOSE mode with message groups; volume and settings reorganised
    - 16 messages in 4 groups of 4 (up to 5 s each); old messages 1-4
    become group 1, and names, recordings and prompts are migrated.
    - New CHOOSE mode for choice-making by scanning: groups chosen by staff
    or by the student (groups first, then messages plus "Back"), and
    choosing by press-twice or hold-and-release. IR mode can also let the
    student scan the codes. This replaces SPEAK's Scan play style.
    - Volume is now a setting (first on SETTINGS and the setup page); B-hold
    in SPEAK moves to the next group. Settings are split into SETTINGS
    (everyday) and SETTINGS 2 (set once per student).
    - The setup page's regular status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
    [TalkingSwitch.ino]
2026-09-26 Quick messages and Topics; settings in each mode; one button rule
    - SPEAK plays 4 Quick messages; CHOOSE scans 4 Topics of 4 messages
    (topics chosen by staff or student, press twice or hold & release).
    - Each mode ends its B list with a "Settings" item: hold A opens that
    mode's own settings. The general SETTINGS mode keeps volume, press
    timing, power, recording boost and Bluetooth.
    - One button rule everywhere: A = next mode / close, B = next,
    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
    [partitions.csv]
2026-09-26 CHOOSE can scan the Quick messages; messages prompt themselves
    - New CHOOSE setting "Choose from": Quick msgs (default) / A topic /
    Topics - replaces "Topics chosen by". Quick messages get spoken
    prompts from their names like topic messages.
    - A message with no prompt yet (e.g. recorded on the stick) plays itself
    quietly as its prompt, cut short by the next offer, so scanning works
    with no setup page.
    - Fix the button-guide function's indentation.
    [TalkingSwitch.ino]
2026-09-26 Name the USB device "Talking Switch" by Magnatronic
    build_opt.h in the sketch folder sets USB_PRODUCT and USB_MANUFACTURER
    for the whole build, so the setup page's connect list and Windows show
    "Talking Switch" instead of the board default "ESP32S3_DEV".
2026-09-26 Setup page: one tab per mode with its settings, volume at the top
    Each mode's tab has its own settings (as buttons, hiding ones that don't
    apply) above its messages, topics, keys or codes. The Switch tab holds
    access, power and voice. Page loudness now uses the switch's Recording
    boost, and voice/speed/loudness can be changed in the message editor.
2026-09-26 Setup page: tabs are the modes, Settings tab matches the switch
    Drop the separate mode row: each mode's tab says whether the switch is in
    that mode, with a Use button if not. The Switch tab is now Settings, with
    Volume and the rest in the same order as the switch's SETTINGS, including
    Forget BT devices. Setting names match the switch.
2026-09-27 SPEAK can scan its messages; Voice tab; easier typed messages; screen fit
    - SPEAK gets Messages: Staff pick / Student scans; CHOOSE is topics only
    (One topic / All topics). Old CHOOSE-with-Quick setups move to SPEAK.
    - The stick hides settings that don't apply, and its text shrinks or is
    shortened to fit the screen. Volume icon: speaker and 4 equal bars.
    - The switch keeps each typed message's words and voice, so the page's
    new Voice tab can remake them in another voice.
    - Message editor starts on Type words, prefilled; Enter makes the speech;
    typed messages without a name are named after their words.
    - Consistent boxed settings rows; tabs and rows fit on phones.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
    [TalkingSwitch.ino]
2026-09-27 Backup mode: KEYBOARD talks when there's no USB
    KEYBOARD's new "No USB" setting: Bluetooth (as before), SPEAK or CHOOSE.
    With SPEAK/CHOOSE, Bluetooth stays off; after 10 s without USB the switch
    changes to that mode (with a sound and "Backup" on screen) and returns
    to KEYBOARD when USB is back. A staff choice of mode ends the backup.
2026-09-27 CHOOSE can offer Control and My device; Modes can turn KEYBOARD/IR off
    - CHOOSE, All topics, "Also offer": Control (the IR codes, chosen like a
    topic's messages) and/or My device (changes to KEYBOARD for the
    student's AAC device or computer), next to the topics, with prompts.
    - SETTINGS "Modes": All / Talking + IR / Talking + KEYBOARD / Talking
    only. A skips modes that are off, the setup page hides their tabs, and
    their settings go too; keys and IR codes are kept.
    [TalkingSwitch.ino]
2026-09-27 Rename modes QUICK/TOPICS/CONTROL; standard screen layout; About, Brightness, switch name
    - Modes are named after what they hold: QUICK, TOPICS, KEYBOARD, CONTROL.
    - TOPICS (All topics): Offer Quick / Offer Control / Offer My device.
    - Every stick screen uses the same three lines, fonts and colours; one
    header font; "Empty" instead of "Nothing to choose".
    - SETTINGS: B button sound (Say it / Off, no beep for empty items),
    Brightness, and About (version, storage, presses).
    - Switch name for Bluetooth and USB, set on the setup page (replaces
    build_opt.h; the USB name is now set at run time).
    - Setup page: About this switch, a storage warning, and a warning when
    the page and firmware ve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
    [TalkingSwitch.ino]
2026-09-27 Keep the stick's ID on the end of a custom switch name
    "Sam's switch" shows as "Sam's switch 7B70", so two switches never
    look the same; custom names are up to 16 characters to fit Bluetooth.
2026-09-27 Switch name: always "ChatterSwitch XXXX", with an optional name in front
    "Sam" on the setup page shows as "Sam ChatterSwitch 7B70" for Bluetooth
    and USB (up to 10 characters in front).
2026-09-27 Silent B, hold B to hear; TOPICS shows each topic and can open it
    - B no longer plays anything (saves battery); hold B plays the selected
    Quick message, IR code's sound, or message in an open topic. The
    B button sound setting goes.
    - TOPICS shows the topic B is on and its messages. Hold A opens it: B
    then steps through its messages and A closes it (or 30 s untouched).
    [TalkingSwitch.ino]
2026-09-27 QUICK: Count presses - press 1-4 times quickly for message 1-4
    New Messages choice with a Press gap setting (0.5/0.8/1.2 s). Each press
    ticks and lights the LED in that message's colour, the screen shows the
    message reached, and it plays when the gap ends. Ignore repeats only
    filters bounces under 0.15 s in this mode.
2026-09-27 ToFTest: try the Unit ToF4M as a touch-free switch
    A separate test sketch: live distance, a trigger line and press count,
    reliability stats, and serial output for plotting. Needs Pololu's
    VL53L1X library.
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2026-09-27 ToFTest: on-screen graph, ~50 readings a second, one reading presses
    Catches a quick wave across the sensor; output in the Serial Plotter's
    name:value format.
2026-09-27 ToFTest: MOVE mode for small movements, zooming graph, finer margins
    - MOVE: press on a 5-30 mm movement towards the sensor from a learnt
    resting distance - for finger-sized movements.
    - LINE: more distances; let-go margin is 10% (min 4 mm) instead of 15 mm.
    - Keeps close-up readings the sensor flags as min-range-clipped, and
    reads every 15 ms in Short range, so a finger is missed less.
    - The graph zooms to what's shown, so small movements are visible.
    [ToFTest.ino]
2026-09-27 ToFTest: MOVE settles after being pressed and still (Off/1/2/3/5 s)
    A finger that stays forward becomes the new resting place and lets go,
    without counting another press, so it can't stay stuck pressed.
    [ToFTest.ino]
2026-09-27 ToFTest: sensor settings screen - Follow, Ignore beyond, Field of view, Smoothing, Too close, Range
    Hold B opens the settings (B next, hold A change, A close), as on
    ChatterSwitch.
    [ToFTest.ino]
2026-09-27 ToF sensor as a touch-free switch in ChatterSwitch
    - Found by itself at start-up on the Grove port; its press feeds the
    student switch, so every mode and setting works with it.
    - Settings (only with a sensor): Sensor mode (Line / Move), Distance,
    Movement, Settle, Follow, Ignore beyond. Fixed: Short range, 15 ms
    readings, full field of view, no smoothing, too close = pressed.
    - SETTINGS > Sensor test: a live graph with a press count (presses only
    beep there). No switch LED and no sleep while a sensor is used.
    - Setup page: the sensor settings on the Settings tab with a live graph
    and Record (download as CSV). FW_API / PAGE_API 2.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
    [TalkingSwitch.ino]
2026-09-27 Docs: a jack switch goes on the Grove cable's yellow wire (GPIO10)
2026-09-27 About opens with hold A: version, name, storage, presses, input
    The About and Sensor test items say "Hold A to open"; A closes.
2026-09-27 Sensor Settle: allow for sensor noise, settle on the average; stray lost readings don't end a press
    - Still = all readings since the still period began within 6 mm (or half
    the Movement), not within 4 mm of the first reading - noise kept
    restarting the timer, so it never settled.
    - The new resting place is the average over the still period.
    - While pressed, lost readings only let go after ~150 ms of them.
    - Sensor test ticks when it settles. Same fixes in ToFTest.
    [TalkingSwitch.ino, ToFTest.ino]
2026-09-27 Sensor Settle: settle after the Settle time pressed, not after stillness
    A relaxed finger creeps and the sensor wobbles, so waiting for the hand to
    be still kept restarting. Now after being pressed for the Settle time,
    where the hand is (a short average) becomes the resting place and it lets
    go. Same in ToFTest.
    [TalkingSwitch.ino, ToFTest.ino]
2026-09-27 USB name via the sketch's own USB serial; docs reviewed and corrected
    - USB CDC On Boot: Disabled - the firmware starts its own USB serial port
    after naming the USB device, so the Connect list shows the switch's name
    instead of ESP32S3_DEV. sketch.yaml updated; a warning if left Enabled.
    - README: board settings, staff buttons (hold A/B, what A closes), the
    TOPICS screen, sleep with the sensor, MAX_SECONDS (5), FW_API (2), the
    Quiet playback and Big switch troubleshooting, a Connect-name entry,
    and what's been tested on hardware.
    - Firmware notes and page help texts brought up to date; the page's About
    box shows the input (switch or ToF sensor). Compiles in both USB modes.
    Co-Au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
    [TalkingSwitch.ino]
2026-09-28 Add brick.stl (3D model exported from OpenSCAD)
    [brick.stl]
2026-09-28 Remove brick.stl from the repository (kept locally, now ignored)
    [brick.stl]
2026-09-28 USB: create the serial port before the keyboard
    With CDC On Boot disabled the keyboard was created first, so the serial
    port became the USB device's second interface; keep it first, as it was
    with CDC On Boot, which Windows remembers.
2026-09-28 Look for the ToF sensor with M5Unified's I2C, released cleanly
    The no-sensor path started and then ended Arduino's Wire on the Grove
    pins, which never ran on hardware before and seems to stop start-up (the
    switch stayed as the chip's USB JTAG port). Now M5Unified's own I2C looks
    for the sensor and is released cleanly; Wire only starts once it's found.
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2026-09-28 README: after an upload, press the power button if it's stuck in download mode
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2026-09-29 Setup page: settings fold into a chip bar, 3-step sound editor, grouped Settings; stick: re-record asks first, hold B steps a setting back
    - Each mode tab: one line with In use / Use, current settings as chips, and a settings button; help behind "?"
    - QUICK's Messages + Choosing shown as one "Plays" setting on the page
    - Rows: Play, Edit sound, and a ⋯ menu (Listen here, Download, Delete); click a row to select it
    - Sound editor: Make it / Check it / Save to switch, with "Not saved yet" and a warning on close
    - Settings tab in groups (Sound, Presses, ToF sensor, Screen and power, Switch, About)
    - Stick: holding A on a recorded Quick message asks "Hold A again to replace"; hold B in setting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
    [TalkingSwitch.ino]
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2026-09-30 README: compile errors from choosing the Nano ESP32 board
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2026-09-30 ChatterSwitch: MOUSE mode (off by default) - motion sensor moves the pointer, switch clicks, hold to pause
    From MouseTest: calibrate (Keep still + Tip down), speed, speed-up, steady,
    smoothing, dwell click, left/right button, flip. New: Hold to pause (switch
    held 2 s pauses / moves; short presses click on release; Off = drag), hold A
    pauses, B steps to Calibrate. Bluetooth runs in MOUSE too (same pairing).
    Setup page: MOUSE tab with Calibrate, Pause and settings; FW_API/PAGE_API 3.
    [TalkingSwitch.ino]
2026-09-30 MOUSE step 2: training on the user's own movements, per-side speed
    Calibrate is now Keep still, then Right, Left, Down, Up (each as far as is
    comfortable). It learns whatever two movements are used (head or wrist) and
    each side's range, so each side gets its own speed. Speed is now the distance
    for a full comfortable movement. Flip settings removed. No turn limit: the
    screen edge re-centres, as agreed. Setup page: live movement picture
    (MSTREAM), learnt ranges in INFO. FW_API / PAGE_API 4.
    [TalkingSwitch.ino]
2026-09-30 MOUSE: a missed Left or Up step copies the other side's range
    [TalkingSwitch.ino]
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2026-10-28 GAME: what the XAC needs, tested one at a time: no charging and a gamepad-only device (100 mA not needed); fix charging staying off after a restart
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2026-10-29 GAME: Send by Wireless - ESP-NOW to the GameDongle, with pairing (FW_API 11)
    Stick: "Send by: USB / Wireless" and "Pair dongle" in GAME settings (PAIR on the
    page). Wireless keeps the USB keyboard + mouse and charging; the radio is on only
    in GAME. Sent on change and every 100 ms; delivered packets = "found" on screen.
    Dongle: pairs with a new stick by itself, or after its button is held 3 s; only
    takes its stick's packets; LED red/green swap fixed. Tested on the PC: pairing,
    and movement through the dongle's gamepad.
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
